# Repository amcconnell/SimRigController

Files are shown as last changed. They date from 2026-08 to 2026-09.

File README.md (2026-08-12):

# SimRigController

A Raspberry Pi appliance that turns Gran Turismo 7 telemetry from a PS5 into haptic feedback through bass shakers mounted to a sim-racing rig. The Pi listens for GT7's UDP telemetry on the LAN, derives audio effects (road bumps, engine rumble, brake/rev-limiter/wheel-slip buzz, gear-shift thumps) from packet contents in real time, and outputs to a shaker amp through a 3.5 mm jack (or DAC). A small web UI on the Pi lets you tune everything live from a browser or phone.

Originally built to replace a Windows tablet running SimHub just for shaker effects.

---

## How it works

```
PS5 (GT7)  ──UDP/33740──►  Pi 4 (shaker app)  ──audio──►  Fosi TP-02  ──speaker wire──►  bass shaker(s)
                                  ▲
                                  │ HTTP :80
                                  ▼
                            Browser / phone
                            (http://simrig-pi.local)
```

Inside the Pi, one Python process runs everything: an asyncio UDP client that decrypts (Salsa20) and parses GT7 packets, a FastAPI web app that hosts the tuning UI, and a PortAudio thread that mixes the configured effects.

Output is mono by default. Set `output_channels = 2` and the mix splits front/rear —
channel 0 (left) drives a front shaker, channel 1 (right) a rear one. Road vibration and
wheel slip are split by axle from real per-corner telemetry; the remaining effects are
placed with a per-effect bias slider. Setting it back to 1 reproduces the single-channel
output exactly, so it is a genuine escape hatch rather than a re-tune.

---

## Hardware

- **Raspberry Pi 4** (other Pi models work, but the deploy targets aarch64).
- **Bass shaker amp** — anything taking a line-level input and driving a shaker works.
  For front/rear you need *two amplifier channels*. Count the **speaker binding posts, not
  the input jacks**: mono subwoofer amps commonly have two RCA inputs that are summed
  internally to one channel, which merges front and rear back together.

  The rig here runs a **Fosi Audio V1.0G**: 2 channels, 50 W + 50 W, 2–8 Ω, 20 Hz–20 kHz
  ±1 dB, **input sensitivity ≤ 280 mV**, 19 V 4.74 A supply (12–24 V accepted),
  130 × 100 × 35 mm. Note the sensitivity — see [Audio output](#audio-output).
- **One or two bass shakers.** Two only helps if they are mounted somewhere your body can
  tell apart — a pedal deck and a seat work well, since that is feet versus back rather
  than asking you to localise a 50 Hz wave in space. On a bridged (BTL) stereo amp, wire
  **one shaker per channel**; two in parallel halves the impedance below what most boards
  tolerate.
- **A USB DAC** — see [Audio output](#audio-output). Worth having.
- **Ethernet or Wi-Fi** on the Pi, on the same LAN as the PS5.

---

## Audio output

The Pi's 3.5 mm jack is a **PWM-derived headphone output at roughly 0.4 V RMS**, where a
line output is about 2 V. A **class-compliant USB DAC** (~$10–30) gives you the latter, and
one with RCA outputs also removes the 3.5 mm splitter from the chain, which is worth doing
on its own.

On this rig the DAC was what finally produced usable output. Worth saying plainly, because
the datasheets do not predict that: the V1.0G is specified to reach rated output from
280 mV and the Pi's jack nominally clears that, so on paper the converter should have been
the only thing that changed. It was not. Treat published sensitivity figures as best-case
numbers and the Pi's PWM level as approximate — neither survives contact with a real rig,
and the amplifier's own volume control is the only calibration that counts.

Two things do come free with the swap. Getting off the PWM output improves low-level
linearity, which is where quiet road texture lives; and a DAC with **RCA outputs** deletes
the 3.5 mm splitter, a part that already cost an evening here when one conductor turned out
to be dead and presented as the software failing to separate channels.

Set the device by name substring in the UI (`aplay -l` to find it). Restart-required, so
the app bounces itself.

**USB adapters routinely enumerate attenuated.** The C-Media dongle used here comes up at
**-20 dB** — quieter than the Pi's own jack, and indistinguishable from "the DAC made no
difference", because nothing in the app can see it. The `simrig-alsa` unit installed by the
deploy sets output levels at boot, before the shaker service starts; see
`simrig_alsa_levels` in the `shaker_app` role. If a new adapter is quiet, check
`amixer -c <card> scontrols` first.

**Gain structure**, in order:

1. **Source at unity** — the DAC's own mixer at 100%, so the full converter range is used.
2. **Absolute level at the amplifier.** Set it once and mark the knob: everything tuned in
   software afterwards is relative to it.
3. **`master_gain` below the limiter.** If peaks sit at the ceiling the limiter clips the
   top off every transient, and the contrast between road texture and a kerb strike — the
   thing the effects exist to convey — goes flat. Around 0.5 suits a line-level source.
   **Diagnostics → Output limiter** measures this rather than leaving it to feel: it reports
   gain reduction in dB and the share of recent time spent reducing. Occasional reduction on
   the biggest hits is the limiter doing its job; reducing through most corners means the
   rig is being compressed, and the fix is less `master_gain` and more amplifier.
4. **`rear_gain_trim`** for the mechanical asymmetry between the two mounting points, then
   the per-effect bias sliders for placement.

Judge trim with **Test wiring**: both its pulses are identical in software and bypass
master gain, trim and the limiter, so any difference you feel is the rig rather than the
settings. Verify the trim you then set with **Test rev limit**, which is centred and goes
through the full chain.

**Run Test wiring before trusting any routing.** Nothing in software can detect reversed
speaker leads, and a swapped pair inverts every routing decision in a way that reads as
"feels subtly wrong" rather than as a fault.

---

## Pi setup (one-time)

Flash a fresh SD card with **Raspberry Pi Imager**:

1. Choose **Raspberry Pi OS Lite (64-bit, Bookworm)**.
2. Open advanced settings (gear icon) and set:
   - **Hostname**: `simrig-pi`
   - **Username**: `simrig`
   - **Password**: anything you'll remember (you'll need it for `sudo` during `ansible-deploy`).
   - **Wi-Fi** credentials (or use Ethernet).
   - **SSH**: enabled, with your Mac's public key authorized.
3. Boot the Pi, then from the Mac:

   ```sh
   ssh simrig@simrig-pi.local
   ```

   Confirm it logs in without a password prompt. Exit.

> If you use a different hostname or username, edit `ansible/inventory.yml` accordingly — `simrig-pi.local` and `simrig` are baked-in defaults the playbook assumes.

The Pi only needs SSH access and password-protected `sudo`. The deploy creates a separate unprivileged `shaker` user that the service runs as.

---

## Controller (Mac) setup

```sh
brew install ansible uv node
make ansible-deps        # one-time: pulls ansible.posix collection
make frontend-install    # one-time: installs npm deps for the UI
```

---

## Deploy

```sh
make ansible-deploy
```

This will:
- Install system packages (`libportaudio2`, `rsync`, etc.) on the Pi.
- Install [uv](https://docs.astral.sh/uv/) and pin it to a known version.
- Build the React UI on the Mac and rsync the bundle to the Pi.
- Create the `shaker` system user and `/opt/simrig/shaker/`.
- Run `uv sync --frozen` on the Pi to build a Python venv.
- Install and start the `shaker.service` systemd unit.

You'll be prompted once for the Pi's `sudo` password. The deploy is idempotent — re-running it is the normal way to ship code changes.

When it finishes, open **http://simrig-pi.local** on any LAN device.

### Useful targets

| Command | What it does |
| --- | --- |
| `make ansible-ping` | Confirms SSH/Python connectivity to the Pi. |
| `make ansible-check` | Dry-run with diff, no changes applied. |
| `make ansible-deploy` | The real thing. |
| `make frontend-build` | Build the UI bundle locally (chained by `ansible-deploy`). |
| `make frontend-dev` | Vite dev server, proxies `/api/*` to the live Pi. |
| `make dev` | Run the Python service locally on the Mac (for backend hacking).|
| `make test` / `make lint`  | Python tests / ruff. |

---

## Using the app

1. Make sure GT7 is **running on the PS5** and you're in an active session.
2. Open **http://simrig-pi.local** — the status pill should switch from `discovering` to `connected` within a few seconds.
3. The default profile is read-only — click **+ New** to create a tunable profile.
4. Drag sliders to taste; changes save automatically (~300 ms debounce).
5. The test buttons at the top of each effect fire a synthetic input so you can verify the audio path without driving — useful for setting a baseline gain.
6. On two channels, run **Test wiring** first — it pulses the front shaker, pauses, then the
   rear, bypassing every effect. Nothing in software can detect reversed speaker leads, and a
   swapped pair inverts every routing decision in a way that reads as "feels subtly wrong"
   rather than as a fault.

**Profiles** are named snapshots of the *tuning*. The built-in `default` profile lives in
code and can't be edited or deleted. Use them to keep separate tunings per car or per driver;
switching activates one instantly.

Profiles deliberately do **not** carry the **Rig** screen — audio device, sample rate, buffer,
output channels and rear trim. Those describe the machine rather than how you want it to feel,
and they do not stop being true because you switched from a GT3 setup to a road car. Keeping
the line there is what stops activating a profile from resetting a stereo rig to mono, and
what would let a profile mean the same thing on somebody else's hardware.

**Mute** toggles output without changing any config — useful for phone calls. It's in-memory
only and resets if the service restarts.

---

## Measuring instead of guessing

Tuning by feel has a specific failure mode: you are always comparing against a memory of a
different track, in a different car, days ago. Two tools exist to replace that.

**Diagnostics → Output limiter** reports gain reduction in dB and the share of recent time
spent reducing. Occasional reduction on the biggest hits is the limiter doing its job;
reducing through most corners means the mix is being compressed rather than driven, and the
symptom is not distortion but sameness — kerbs, shifts and road texture all arriving at one
level. That reads as "flat", whose obvious remedy is more gain, which makes it worse.

**Diagnostics → Session recording** captures every packet at full rate to
`recordings/session-*.jsonl`. Whole packets, including the menu and paused frames the app
itself discards, so a replay exercises the same gates the live path does. It stops itself at
256 MB.

`scripts/replay.py` then renders a recording back through the real DSP offline — no audio
device involved — so the same lap can be measured under two settings:

```sh
python scripts/replay.py recordings/session-20260807-1830.jsonl
python scripts/replay.py <file> --set master_gain=1.0
python scripts/replay.py <file> --profile "Gr.3" --against "road car"
python scripts/replay.py <file> --wav /tmp/lap.wav
```

Packets are scheduled by `packet_id`, GT7's physics frame counter, so replay is immune to
network jitter and two runs of one file are bit-identical.

Watch **crest** — peak over RMS — rather than peak. The limiter pins peak to the ceiling by
construction, so two settings that feel completely different report the same peak. Crest is
what collapses when a mix is being compressed:

```
delta (B - A)
   ch0: rms  +1.76 dB   crest  -1.65 dB
limiter: duty +52.0 pts   peak +18.06 dB

B is louder but flatter — dynamic range traded for level.
```

### Front/rear isolation

Two accelerometer pods (ADXL345 on I2C, `0x53` front and `0x1D` rear) measure what the rig
actually delivers. **Diagnostics → Accelerometer pods** shows live orientation and vibration;
**Measure crosstalk** pulses each shaker alone and reports how much reaches the other pod.

Read the **isolation** figure, which is the mean of the two directions. Per-pod sensitivity
error enters the two directions as reciprocals and cancels in the mean, so that number is
right even with the pods uncalibrated or badly matched — only the asymmetry between
directions carries the mismatch.

This matters more than it sounds. Below about 100 Hz a body does not localise a source; it
reports which part of itself is loaded, feet or back. So energy from the pedal deck arriving
at the seat is *felt as rear*, which is the exact cue the two-channel split exists to carry.

The rig here measures **-4.2 dB** — a seat plate bolted to a 1" hot-rolled steel frame, which
is close to an ideal transmission path at these frequencies. Isolating the plate would want
about 5 mm of static deflection under seated load to put the isolator's natural frequency near
7 Hz, and that compliance is felt every time you brace against the brake pedal.

The cheaper answer is to stop relying on position. Road vibration carries **separate noise
bands per channel** — rear low, front high — so the two ends differ in character rather than
location, which is the distinction a body still makes when the frame has mixed them together.

Be clear that this is a fiction: no road puts a particular frequency under one axle. It buys
discriminability at the cost of realism, and it is off by default (both channels ship with the
same 44-50 Hz and 60-80 Hz bands). The discrete effects have always been coded this way —
brake at 30 Hz, gear shift at 44, rev limiter at 75, slip at 90/65 — so the vocabulary already
exists; extending it to the continuous bed is the part worth deciding deliberately.

---

## Configuration

The Pi stores two config files in `/opt/simrig/shaker/config/`:

- **`shaker.toml`** — the live config (`[gt7]`, `[web]`, `[audio]` sections). The audio section is overwritten when you activate a profile. Edits via the web UI write here.
- **`profiles.json`** — your named profiles and the currently-active one. Created on first deploy, never overwritten on re-deploy.

You can SSH in and edit `shaker.toml` directly; the service watches the file and reloads on save. Restart-required changes (web host/port, audio device/sample-rate/buffer) trigger a clean systemd restart.

---

## Repo layout

```
SimRigController/
├── ansible/                 # Idempotent deployment to the Pi
│   ├── inventory.yml
│   ├── site.yml
│   └── roles/{base,python_runtime,shaker_app}/
├── apps/shaker/             # The Python app
│   ├── src/shaker/
│   │   ├── audio/           # Effect generators + mixer
│   │   ├── gt7/             # Salsa20 decrypt + packet parser + UDP client
│   │   ├── web/             # FastAPI + built React bundle
│   │   ├── config.py        # AudioConfig / Config dataclasses
│   │   ├── profiles.py      # Profile CRUD
│   │   └── runtime.py       # asyncio orchestrator
│   ├── tests/
│   ├── frontend/            # Vite + React + TS + Tailwind UI source
│   └── config/shaker.toml   # Default values shipped with the repo
└── Makefile
```

---

## Credits

The GT7 telemetry protocol (UDP port, Salsa20 key, packet layout) is community reverse-engineering; the Python port here is based on prior work from [gt_telem](https://github.com/snipem/gt-telem) and PDTools.

---

## License

MIT — see [LICENSE](LICENSE).

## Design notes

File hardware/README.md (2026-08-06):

# Hardware

Printable parts for the rig.

## Which files to edit

**`ADXL_Pod_PD.FCStd` is the model.** It is a PartDesign document: open it in
FreeCAD, edit the `Params` spreadsheet, and every sketch follows. Sketches are
constrained and bound to spreadsheet aliases by expression, and each attaches
to an origin plane rather than to a face of an earlier feature — face
references are what make PartDesign models break when something upstream
changes size.

`build_adxl_pod_pd.py` built it once and is kept only to show the layout. It is
not re-run; the `.FCStd` is the source now.

`adxl_pod.py` is the earlier Part-primitive implementation. Kept as a
reference for the geometry rationale and because its assertions document the
two collisions found during design. **Read-only** — edits go in the PartDesign
model. Regenerate its own output, if ever needed, with
`freecadcmd hardware/adxl_pod.py`.

Both produce the same part: pod 34.31 cm^3 in each, lid within 0.01 cm^3.

After editing the model, re-export `ADXL_Pod_PD.stl` and `ADXL_Pod_PD_Lid.stl`
for slicing.

## ADXL345 sensor pod

Bolt-on enclosure for a GY-291 ADXL345 breakout, with an RJ45 keystone jack for
a Cat5 drop back to the Pi. One pod per contact point — seat pan and pedal deck.

Part of the accelerometer feedback loop: the shaker app has no input, so every
level it reports is the buffer it computed, upstream of the DAC, amp and
transducer. It reads identically whether a shaker is working or its cable is
cut. An accelerometer on the frame is what turns "does this feel balanced?"
into a number.

| | |
| --- | --- |
| Outer | 66 x 40 x 36 mm, ~43 g pod + ~12 g lid in PLA |
| Rig bolt | M5, counterbored so the head finishes below the board |
| Board | GY-291, 15.0 mm hole spacing, M2.5 heat-set inserts |
| Jack | AMPCOM HKJ-801M keystone, 14.7 x 19.6 aperture, 2 mm local wall |
| Lid | Snap-fit, 0.4 mm bead with a 0.45 mm lead-in ramp, pry notch |

### Assembly

1. Heat-set two M2.5 inserts into the pedestal.
2. Punch the keystone down onto short **solid-core** pigtails — IDC terminals
   bite solid wire, and stranded works loose under vibration. Snap the jack in
   from outside.
3. Bolt the pod to the frame **before** fitting the board; it covers the
   counterbore.
4. Screw the ADXL345 down, wire it to the pigtails, snap the lid on.

Second pod ties SDO high for I2C address `0x1D`; both share one bus.

### Things that are load-bearing, not stylistic

- **The pedestal.** Mount stiffness *is* the measurement. A compliant path adds
  its own resonance, and if that lands under ~120 Hz it reads as rig behaviour.
  The walls are a shell and carry nothing.
- **The counterbore.** It exists so the board can straddle the bolt rather than
  stand off above its head — which would rebuild the compliance the pedestal is
  there to avoid.
- **The 2 mm wall at the aperture.** Keystone latches are made for wall-plate
  stock and will not grip 3 mm.
- **The tight snap groove.** A rattling lid is a noise source on a part built to
  measure vibration. If it still rattles once printed, damp it with tape.
- **The bead's lead-in ramp.** Insertion and removal should not be the same
  fight: the ramp deflects the lip gradually on the way in, while the square
  top shoulder still does the retaining. If the lid ends up too loose, raise
  `BEAD` rather than removing the ramp — that restores grip without making it
  hard to fit again.

### Before printing 55 g

The keystone snap and the lid snap both come from drawings rather than calipers,
and both sit within FDM tolerance of not fitting. Slice the first 5 mm in X (the
keystone wall) and a short length of lid rim, and check the fits first.

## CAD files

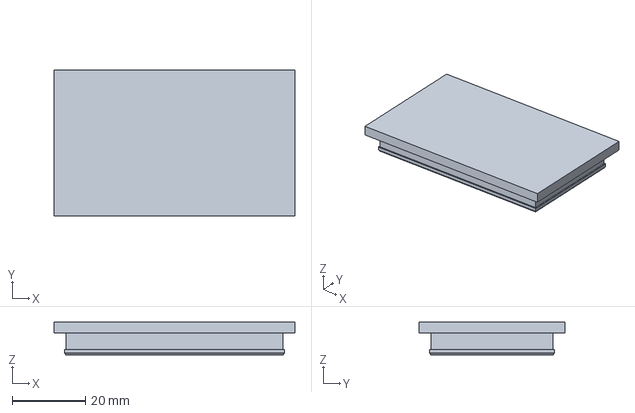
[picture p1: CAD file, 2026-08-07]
hardware/ADXL_Pod_PD.FCStd
66.0 x 40.0 x 9.00 mm

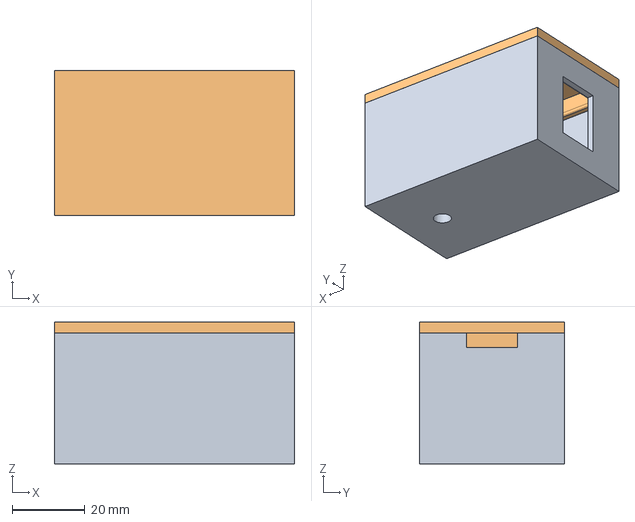
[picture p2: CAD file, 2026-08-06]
hardware/ADXL_Pod.FCStd
66.0 x 40.0 x 39.0 mm
Pod
Lid

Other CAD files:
hardware/ADXL_Pod_PD_Lid.stl
hardware/ADXL_Pod_Lid.stl
hardware/ADXL_Pod.3mf
hardware/ADXL_Pod.stl
hardware/ADXL_Pod_PD.stl

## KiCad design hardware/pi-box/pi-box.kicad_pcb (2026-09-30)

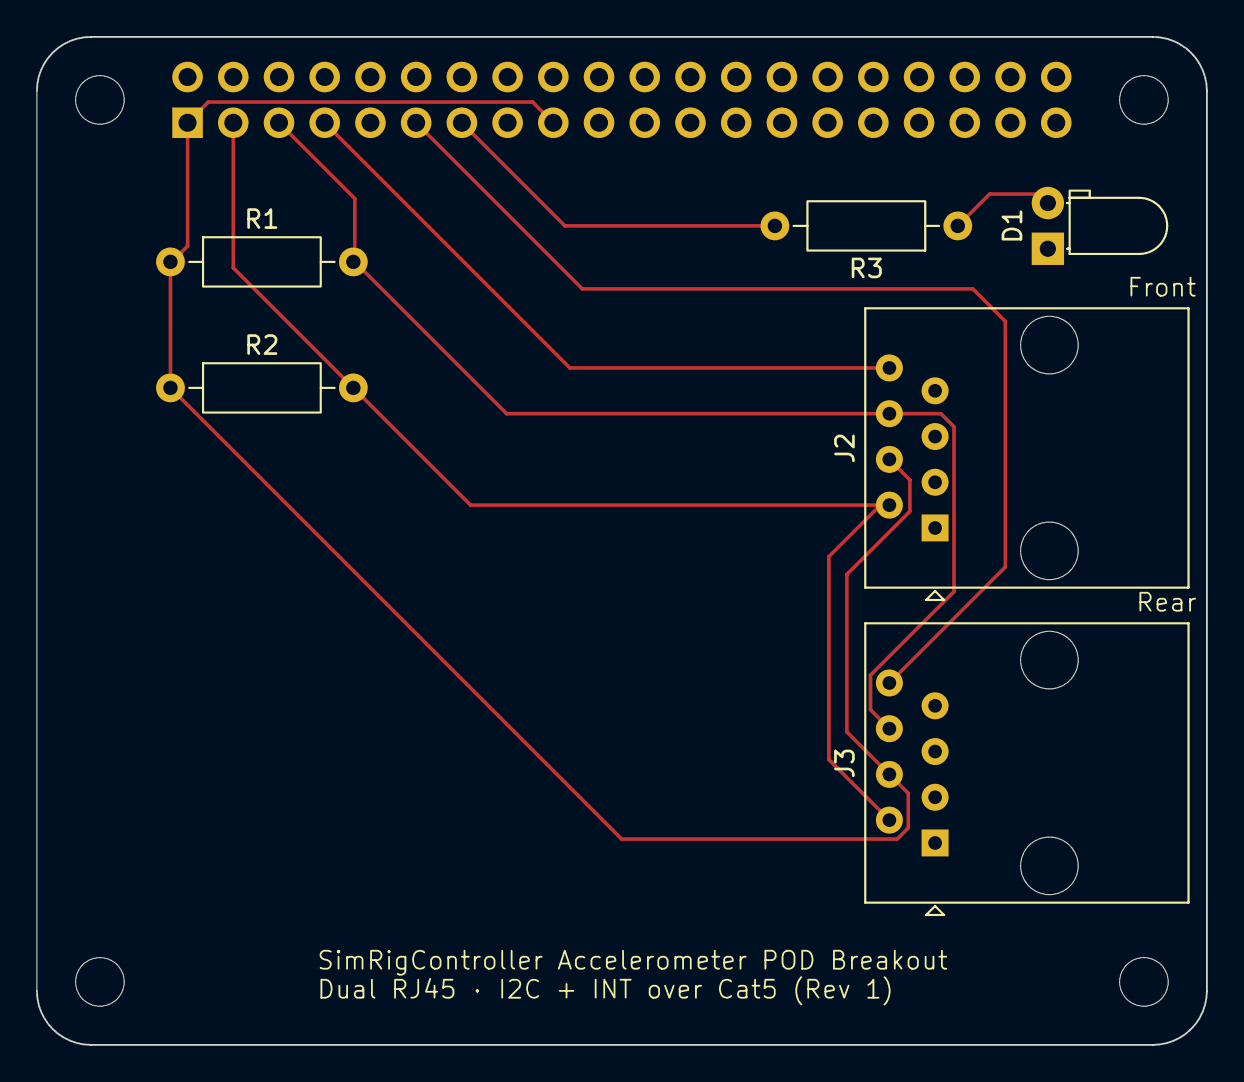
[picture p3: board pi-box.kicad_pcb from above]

Board: 2 copper layers, 65.0 x 56.0 mm, 11 parts (1 on the bottom side), 8 nets.

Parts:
D1: LED; LED_D3.0mm_Horizontal_O1.27mm_Z10.0mm
J1: Raspberry_Pi_4; PinSocket_2x20_P2.54mm_Vertical
J2, J3: RJ45; RJ45_Amphenol_54602-x08_Horizontal
MH1, MH2, MH3, MH4: MountingHole_2.7mm_M2.5
R1, R2: 3.3k; R_Axial_DIN0207_L6.3mm_D2.5mm_P10.16mm_Horizontal
R3: 1k; R_Axial_DIN0207_L6.3mm_D2.5mm_P10.16mm_Horizontal

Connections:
+3.3V: J1.1 (3V3), J1.17 (3V3), J2.4, J3.4, R1.1, R2.1
/INT_FRONT: J1.7 (GPCLK0/GPIO04), J2.8
/INT_REAR: J1.11 (GPIO17/SPI1_~CE1), J3.8
/SCL: J1.5 (SCL_I2C1/GPIO03), J2.6, J3.6, R1.2
/SDA: J1.3 (SDA_I2C1/GPIO02), J2.2, J3.2, R2.2
GND: D1.1 (K), J1.6 (GND), J1.9 (GND), J1.14 (GND), J1.20 (GND), J1.25 (GND), J1.30 (GND), J1.34 (GND), J1.39 (GND), J2.1, J2.3, J2.5, J2.7, J3.1, J3.3, J3.5, J3.7
unnamed: D1.2 (A), R3.1
unnamed: J1.13 (GPIO27/SDIO_DAT3), R3.2

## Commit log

2026-04-26 Initial commit: GT7 telemetry → bass shaker on Raspberry Pi
    The shaker app receives Gran Turismo 7 telemetry from the PS5 over UDP,
    synthesizes audio (road vibration + gear-shift thumps) and outputs to a
    bass shaker amp. A small FastAPI web UI lets the user tune effects live;
    a config file watcher hot-reloads non-structural changes and exits cleanly
    on restart-required changes.
    Includes idempotent Ansible deployment to the Pi (single playbook, three
    roles: base packages, uv-managed Python runtime, shaker_app with systemd).
2026-05-16 Sharper bumps, engine presence, speed-responsive vibration
    Audio quality pass after first IRL sessions on the Pi.
    Bus changes:
    - Per-corner 1-pole HPF (~6 Hz) on suspension + max across corners,
    replacing avg + rolling-mean deviation. Single-wheel kerb hits no
    longer get smeared into the noise floor.
    - Drop packets when `is_paused` or `not is_on_track`, alongside the
    existing `lap_count < 0` filter — no more menu / pre-race audio.
    - Expose `throttle` and add a triangular engine-RPM/throttle sweep
    override for the new test button.
    Effects:
    - New `EngineRumble` — continuous-phase sine, frequency from RPM via
    configurable divisor, amplitude from throttle. Adds the chassis
    thru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
2026-05-16 Add brake rumble, rev limiter, wheel slip effects + test buttons
    Three new continuous-sine effects driven by previously-unused telemetry,
    plus per-effect test triggers so they can be verified without GT7.
    - TelemetryFeatures gains `brake` (0..255) and `slip_magnitude` (max
    per-corner |wheel_rps × tire_radius − speed_mps|).
    - Triangular-ramp test overrides for brake input, rpm percentage, and
    slip magnitude, accessed via `current_brake() / current_rpm_pct() /
    current_slip_magnitude()` which fall through to the feature values
    outside the test window. Same pattern as the engine sweep.
    Effects (all continuous-phase sine + smoothed amplitude):
    - BrakeRumble: ramps linear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
2026-05-16 Full UI rewrite + profiles + system-wide mute
    UI redesign
    - Drop the hand-rolled HTML form for a Vite + React + TypeScript + Tailwind
    SPA living in apps/shaker/frontend/. Source files in frontend/src/; build
    output (gitignored on the controller, committed) lands in web/static/.
    - Sticky StatusBar with connection pill, packets/sec, speed, RPM, gear,
    throttle/brake, lap. Trailing slot hosts the Mute button.
    - Collapsible EffectCard per effect — Enabled + Gain visible by default,
    remaining knobs behind a ▸ expander. iOS-style toggle replaces the
    Enabled checkbox; sliders accompany every bounded numeric field; a Hint
    ("?") component reveals tooltip copy for non-obvious knobs and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
2026-05-19 Silence shaker output when telemetry stops arriving (#1)
    Until now the bus's "ignore packets when not driving" filter only
    fired on packets GT7 actually sent — menus, paused, off-track. When
    GT7 exits entirely the PS5 stops sending packets at all, so the
    filter never ran and the last in-session features kept driving the
    shaker indefinitely.
    Adds a watchdog task to GT7Client that fires an `on_stale` callback
    when no packet has arrived for >2 s. The runtime wires it to a new
    `AudioBus.reset_features()` method that clears derived state — same
    behavior as a menu-packet rejection. Idempotent so the watchdog can
    re-fire while telemetry stays away without ill effect.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
2026-07-06 Pin telemetry to the locked console; rediscover after 30s silence
    Anything on the LAN can stream packets to :33740 and the shaker would
    play them — racetrace's UDP session replayer does exactly that when the
    Pi's discovery broadcast reaches it, so the rig kept shaking after the
    real driving session ended, replaying a recorded lap nobody asked for.
    _on_datagram now drops packets from any source other than the
    configured/discovered console IP (logged once per rogue source). A
    discovered lock is released after 30s without packets, so a wrong lock
    (a tool that answered our broadcast) or a PS5 on a new DHCP lease heals
    without a service restart; a configured IP is never dropped.
    Also prune th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
2026-07-06 Fix restart-required config changes lost by the write-race fix
    The race fix made save_config update state.config synchronously, which
    turned the file watcher into a no-op for API-driven saves (state
    already matches disk when it fires). That silently killed the watcher's
    needs_restart path for web UI changes: switching audio device, sample
    rate, or buffer size saved the config but never restarted the service,
    so the change didn't take effect until the next unrelated restart.
    Profile activation with differing device settings was broken the same
    way.
    save_config now checks needs_restart itself and sets the restart event.
2026-07-06 Silence the shaker when the telemetry payload freezes
    Exiting a session via GT7's pause menu clears the paused bit but leaves
    on_track set, lap_count >= 0, and the payload frozen at the last
    driving frame (measured live 2026-07-06: rpm 4564 / 172 kph, forever).
    The flag gate passes, so effects kept firing on stale data — wheel slip
    in particular buzzes continuously on a frozen wheel-vs-car speed
    mismatch. This was the "shaker keeps going after I leave the track"
    report.
    Gate on payload freshness too: bit-identical physics fields (position,
    rpm, speed, suspension) for 30 consecutive frames means a menu, not
    driving — reset to silence. Real physics jitters every frame; a parked
    car false-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
2026-08-05 Ignore unknown config keys so a rollback isn't a crash loop
    save() writes every field of the current schema, so a config written by a
    newer build carries keys an older one has never seen. _from_dict passed the
    raw dict straight into the dataclasses, load() at startup isn't guarded, and
    the unit is Restart=always/RestartSec=2 — so rolling back after touching a
    single slider became a 2-second crash loop with no web UI left to fix it
    from. The deploy can't repair it either: shaker.toml is templated with
    force:false and the source sync excludes config/.
    Filter to declared fields and warn, exactly as profiles.get_audio already
    does for the same reason. Recovery from this point forward is a rol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
2026-08-05 Fade gated effects out instead of cutting them to zero
    Every gated effect decayed its smoothed amplitude by half and then returned
    a block of pure zeros. The state faded; the output did not. Coming off the
    brakes stepped the signal from 0.8284 full-scale to silence in a single
    sample, and slip dropping below threshold stepped 0.9999 — measured across
    a sweep of carrier phases, since a single block size can land every boundary
    on a zero crossing and hide it (75 Hz at 20 ms is exactly 1.5 cycles, which
    is why the rev limiter looked clean while being latently broken).
    A step is broadband, and a transducer bolted to the rig frame radiates that
    as a tick you *hear* rather than motion you feel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
2026-08-05 Ride gain on the mix instead of hard-clipping it
    Six effects at gain 1.0 sum well past unity. On a worst-case corner entry —
    rough surface, WOT, rev limiter, front lockup, shifts — 20-27% of samples
    were being hard-clipped, which folds intermodulation products into 120-300
    Hz, a band the clean mix has essentially no energy in. It also inverts the
    dynamics, compressing hardest exactly when the most is happening.
    Replace the clip with a gain-riding limiter: fast attack, smoothed release,
    and the hard clip demoted to a net for within-block excursions the limiter
    cannot see. Attack length was measured rather than guessed — spreading the
    reduction across the whole block still clips 0.103%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
2026-08-05 Split suspension and slip per axle, without touching the audio
    Groundwork for driving the pedal-deck and seat shakers independently. The bus
    already high-pass filtered all four corners separately and then discarded the
    axle information with a four-way max, which is the most useful signal in the
    packet for a two-channel rig.
    TelemetryFeatures gains suspension_activity_front/_rear and signed
    slip_front/_rear. The slip sign is the point: today's slip_magnitude takes
    abs() twice, so a locked front wheel and a spinning rear one produce an
    identical buzz, when they are opposite corrections and the two most useful
    things a driver can be told.
    Nothing audible changes. The legacy scalars are comput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
2026-08-05 Vendor per-car drivetrain layout from the racetrace database
    GT7 sends a car code but nothing about the car, so where the engine sits and
    which axle is driven has to come from outside. Two effects need it: a gear
    shift thumps through the driven axle, and engine rumble belongs wherever the
    engine physically is. Both are currently static guesses, and both are wrong
    for a front-wheel-drive car — 60 of them here get a seat-biased shift through
    an axle that isn't driven.
    The sibling racetrace project already scraped this and keys it by the same
    car code this app receives. Vendored rather than imported: the ansible deploy
    only ships apps/shaker to the Pi, so a runtime dependency on a sibling re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
2026-08-05 Drive front and rear shakers as two channels
    Stages 3 and 4 of the plan, in one commit: the plumbing and the routing share
    a single code path, so splitting them would have meant writing an intermediate
    state that never runs anywhere.
    output_channels = 2 opens a second channel — 0 front (pedal deck), 1 rear
    (seat). Opt-in rather than auto-probed, because ALSA's "default" device accepts
    two channels whether or not anything is wired to the second one, so a probe
    always "succeeds" and would silently send every rear-routed effect to a dead
    conductor. Restart-required, alongside sample rate and buffer size, since the
    channel count is fixed when the stream opens. A PortAudioError on the two-
    cha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
2026-08-05 Place shift and engine effects using the car's drivetrain
    The two effects with no telemetry behind them were fixed guesses: a shift
    thump always went rearward, the engine always sat wherever the slider said.
    Both are wrong for a front-wheel-drive car, which takes driveline shock
    through the axle it actually drives.
    GT7 sends a car code at offset 0x124 but nothing about the car, so the
    vendored drivetrain table supplies the rest. The split of responsibility is
    that the configured bias gives the *magnitude* and the lookup gives the
    *direction* — the slider keeps meaning what its label says, while the end it
    lands on comes from the car. A user who dialled the slider to the "wrong"
    side still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
2026-08-05 Fix inverted wheel rotation sign; slip has never worked
    GT7 sends per-corner wheel rotation negated. Measured on a live console
    2026-08-05: raw * tire_radius tracked -speed_mps to within 1% from 6 to
    184 km/h, across braking, coasting and wheelspin, at a ratio pinned to -2.00.
    The consequence is that slip_magnitude has always read 2 * speed rather than
    actual slip, so with the shipped threshold of 2 m/s and scale of 5 m/s the
    wheel-slip effect saturated above 12 km/h and stayed there. It was not a slip
    cue at all — it was a constant full-amplitude 90 Hz drone whenever the car
    moved, and it was consuming the headroom the limiter then took back off every
    other effect.
    I argued the opposite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
2026-08-05 Judge wheel slip as a ratio of speed, not an absolute m/s
    A tyre responds to slip ratio, not to slip in metres per second — peak grip
    sits near 10-20% however fast the car is going. The old absolute threshold
    could not express that, and was wrong at both ends of the speed range at once:
    10 m/s ( 36 kph): 2.0 m/s = 20.0% slip -> already sliding, no warning
    45 m/s (162 kph): 2.0 m/s = 4.4% slip -> inside normal grip
    80 m/s (288 kph): 2.0 m/s = 2.5% slip -> chatters on every straight
    Same tyre behaviour, opposite outcomes, and no single value fixes both. Making
    the field more configurable would only have handed the impossible choice to the
    user.
    Now gated on both a r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
2026-08-05 Add printable ADXL345 sensor pod
    The physical half of closing the feedback loop. The shaker app has no input:
    every level it reports is the buffer it computed, upstream of the DAC, the amp
    and the transducer, so it reads identically whether a shaker is working or its
    cable is cut. Bolting an accelerometer to the frame is what turns "does this
    feel balanced?" into a number — and would have caught most of the silent
    failures found this week.
    One pod per contact point, seat pan and pedal deck, each on a Cat5 drop back to
    the Pi with an RJ45 keystone. Both sensors share one I2C bus; the second board
    ties SDO high for 0x1D.
    The script is the source and the meshes are build output, for the sam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
    [ADXL_Pod.FCStd, ADXL_Pod.stl, ADXL_Pod_Lid.stl]
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2026-08-05 Identify sway/heave/surge against a live capture
    All three are body-frame accelerations in m/s^2 with gravity excluded.
    Established on a live console rather than assumed, by recording them beside
    two references whose meaning was already settled — d(speed)/dt and
    v * yaw_rate — over 665 samples and 98 seconds:
    surge longitudinal, + accelerating. Straight-line only: r=+0.989,
    scale 0.992. Under braking, -12.50 against -12.42.
    sway lateral, NEGATED with respect to speed * ang_vel_y. Opposite sign
    in 388 of 394 samples above 4 m/s^2 — a convention, not noise.
    heave vertical, gravity excluded. Median exactly 0.00 while calm at both
    36 and 90+ km/h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
2026-08-06 Give the lid bead a lead-in ramp
    The snap was too tight to fit by hand. The fix is not a weaker snap — it is an
    asymmetric one. A square-shouldered bead makes insertion and removal the same
    fight; ramping the leading edge deflects the lip gradually going in while
    leaving the square top face to do the retaining.
    Built as explicit steps rather than a chamfer because FDM discretises a slope
    into a staircase anyway. Modelling it as one makes the printed result
    predictable instead of an artifact of slicer settings.
    Two changes, addressing different causes:
    - the ramp, which fixes the bead specifically
    - LIP_GAP 0.20 -> 0.25, which fixes the lip binding along all 6 mm of its
    length. 0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
    [ADXL_Pod.FCStd, ADXL_Pod_Lid.stl]
2026-08-06 correct STL used
    [ADXL_Pod.3mf]
2026-08-06 Rebuild the sensor pod as an editable PartDesign model
    The Part-primitive version was scripted geometry: the .FCStd held one dumb
    solid with no feature tree, so the only way to change anything was to edit
    Python and re-run. That was the right trade while designing blind against
    datasheets — text diffs, assertions catching collisions — and the wrong one
    now that the part has converged and the owner wants to edit it.
    ADXL_Pod_PD.FCStd is a real PartDesign document and is now the source. Every
    dimension lives in a Params spreadsheet with a named alias, and every sketch
    constraint is bound to one by expression, so changing a number in the sheet
    propagates through both bodies. Verified rathe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
    [ADXL_Pod_PD.FCStd, ADXL_Pod_PD.stl, ADXL_Pod_PD_Lid.stl]
2026-08-07 Stop routing engine placement from the car; persist ALSA output levels
    Three defects, all found by driving the rig rather than by reading the code.
    ENGINE PLACEMENT WAS INVERTED. Drivetrain routing took abs() of the bias and
    picked the side itself, so on a front-engine car dragging the "Front <-> Rear"
    slider toward Rear moved the effect further Front:
    set +0.30 (rear) -> applied -0.30 -> front 65% / rear 35%
    set +0.45 (rear) -> applied -0.45 -> front 72% / rear 28%
    A control must not do the opposite of what its label says. Engine is now never
    routed and always follows its own slider, sign included.
    That is not just a UI fix. Routing engine by physical engine position is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
    [ADXL_Pod.3mf, ADXL_Pod_PD.FCStd]
2026-08-07 Document the audio output chain; restore lost stereo edits
    Adds an Audio output section covering what cost a full evening on the rig: the
    Pi's jack is a PWM headphone output at ~0.4 V against a line output's 2 V, so
    driving an amplifier from it means running every gain stage flat out and still
    wanting more. A class-compliant USB DAC fixes it, and one with RCA outputs also
    deletes the 3.5 mm splitter — which is where the evening actually went, a dead
    ring conductor presenting as "the software isn't splitting channels".
    Records the trap that followed: USB adapters routinely enumerate attenuated.
    The C-Media dongle came up at -20 dB, quieter than the Pi's own jack and
    indistinguishable from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
2026-08-07 Record the amp's specs; correct the DAC's role
    The V1.0G reaches rated output from 280 mV. The Pi's headphone jack already
    clears that, so the earlier explanation for a quiet rig — a 0.4 V source too
    weak to drive the amp — cannot have been right, and the DAC changing nothing
    audible was the evidence rather than a puzzle.
    The likelier fault runs the other way. A 2 V source into a 280 mV input with
    the volume at maximum overdrives it several times over, and clipped bass reads
    as dull rather than distorted, which invites turning it up again. Says so, and
    gives the symptom to check: a top third of the volume travel that does nothing.
    Keeps the DAC recommendation, since removing the splitt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
2026-08-07 Say the DAC fixed it, since it did
    The previous commit reasoned from the amp's 280 mV input sensitivity that the
    Pi's jack must already have been sufficient, and concluded the DAC could not
    have changed the level. On this rig it did — the output was not usable until
    it went in.
    Published sensitivity is a best-case figure and the Pi's PWM level is only
    loosely defined, so the two numbers never supported the conclusion drawn from
    them. Records what happened and leaves the amplifier's volume control as the
    only calibration that means anything, rather than restating the theory.
    Keeps the low-level linearity and splitter-removal arguments, which stand on
    their own, and drops the clipping diag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
2026-09-27 Add the pi-box breakout schematic, in progress
    A small board to replace the jury-rigged GPIO header that has been taking the
    I2C bus down: a 2x20 stacking socket, two RJ45 jacks for the pods, the two
    pull-ups the bus needs, and a status LED. Stacking rather than plain so a DAC
    HAT can go on top later without a respin — this board only touches pins 1, 3,
    5, 6, 7, 11 and 13, and I2S lives on 12, 35, 38 and 40.
    The pull-ups are the part that is not merely tidier. With 4.5 m of Cat5 on the
    bus the SDA rise time against the Pi's internal 1.8k is around 400 ns, well
    past the 300 ns that Fast-mode allows at 400 kHz, so the bus has been out of
    spec since the pods were wired rather than since anyt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
    [pi-box.kicad_pcb, pi-box.kicad_sch]
2026-09-30 Finish the pi-box schematic: clean ERC, verified netlist
    Completes the breakout board that replaces the jury-rigged GPIO header.
    Zero ERC violations, down from 19 at the first run.
    The substance is the two 3.3k pull-ups. With 4.5 m of Cat5 on the bus, SDA's
    rise time against the Pi's internal 1.8k is around 400 ns against the 300 ns
    Fast-mode allows at 400 kHz, so the bus has been out of spec since the pods
    were wired rather than since anything broke. In parallel these give about
    1165 ohms, roughly 257 ns, and 2.8 mA of sink — inside what the ADXL345 is
    specified to handle.
    Also a status LED on GPIO27 through 1k. Driven in software rather than off
    the bus, both because anything hung on S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
    [pi-box.kicad_sch]
2026-09-30 Start the pi-box layout: HAT outline and footprints placed
    Board outline, mounting holes and header position come from KiCad's own
    RaspberryPi-HAT template rather than being drawn by hand — 65 x 56 mm with
    radiused corners, four M2.5 holes at 58 x 49 mm, and the 2x20 socket at
    +8.37, +4.77 from the top-left corner. Deriving that geometry by measurement
    is how a board ends up not fitting.
    The socket is on B.Cu at -90 degrees, matching the template. That matters
    more than it looks: the female header hangs below the board to mate onto the
    Pi's pins, so it is a bottom-side part, and a bottom-side footprint is
    mirrored. On the front layer it fabs perfectly and connects SDA to a ground
    pin.
    Th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
    [pi-box.kicad_pcb, pi-box.kicad_sch]
2026-09-30 Place pi-box components
    Jacks on the short edge facing the same way as the Pi's own ports, 18 mm
    apart and sharing an X so the cables leave in a line. LED beside them, since
    a status light you have to pull a panel to read is one you will never look
    at. Resistors in a column near the header, where their nets already are.
    No overhang, because the DAC HAT is off the table: it uses the whole HAT
    footprint, no stacking header sold gives more than about 8.5 mm of pin above
    the board against the 13.5 mm these jacks need, and with the HAT the audio
    cables leave in the wrong direction anyway. The USB DAC already works and can
    sit wherever it likes. That also means a plain 2x20 socket is enough, thou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
    [pi-box.kicad_pcb]
2026-09-30 Close the pi-box outline: DRC clean before routing
    Deletes the HAT's camera and display ribbon cutouts, which nothing on this
    rig will ever use, and closes the left edge as a single straight segment. The
    display slot was the reason DRC failed: it passed 0.11 mm from J3's SDA pad
    against a 0.5 mm rule, a gap invisible at any sane zoom and one a fab house
    would have resolved by routing through the pad.
    Removing them opened the perimeter, since the left-edge notch was the
    perimeter along that stretch rather than a hole in it. The replacement
    segment initially landed on F.Cu instead of Edge.Cuts — drawn with the
    routing tool rather than the graphics tool — which reads as a copper trace
    sitt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
    [pi-box.kicad_pcb]
2026-09-30 Route pi-box: DRC clean, no vias, unbroken ground plane
    All seven signal nets on F.Cu with zero vias, so the GND zone on B.Cu is a
    single continuous sheet rather than something with slots cut through it. That
    was not really planned — it fell out of placing parts so their nets did not
    need to cross — but it is the best case for a two-layer board and worth not
    undoing during fine-tuning.
    The ground zone connects 17 pads that would otherwise have been 17 hand-drawn
    tracks. Its thermal relief clearance had to come down from 0.5 mm to 0.2 mm:
    at 0.5 the copper could not fit between the header's pads, which sit on a
    2.54 mm pitch with about 0.84 mm between pad edges, so five interior GND pads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
    [pi-box.kicad_pcb]
2026-09-30 Add pi-box v1 fabrication outputs
    The gerbers and drill files as actually sent, kept under fab/v1 so the
    physical board can be identified later without regenerating anything from a
    source tree that will have moved on. Regenerating is not the same as knowing:
    what arrives in two weeks is whatever was uploaded, not whatever the current
    board file happens to plot.
    Drill counts cross-check against the design: 64 plated holes (40 header, 16
    jack pins, 6 resistor, 2 LED) and 8 non-plated (4 jack board-locks at 3.2 mm,
    4 mounting holes at 2.7 mm). Tool sizes match too, which is independent
    confirmation the export captured the whole board rather than a subset.
    No back silkscreen file, correctly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
    [pi-box-B_Cu.gbl, pi-box-B_Mask.gbs, pi-box-Edge_Cuts.gm1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]
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
